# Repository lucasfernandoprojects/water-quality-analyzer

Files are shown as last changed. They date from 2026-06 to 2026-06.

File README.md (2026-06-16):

# ESP32 Water Quality Analyzer

An open-source water quality analyzer built with an ESP32 that estimates the pollution level of water samples by combining three different sensors. Results are displayed in real time on the Arduino IDE Serial Monitor.

> **This project was kindly sponsored by [Elecrow](https://www.elecrow.com/pcb-assembly.html?idd=5) - a leading provider of open-source hardware and manufacturing services. They offer everything from ESP32 development boards to professional PCB assembly, CNC machining, and more. I highly recommend checking them out for your next project.**

<div style="display: flex; flex-wrap: wrap;">
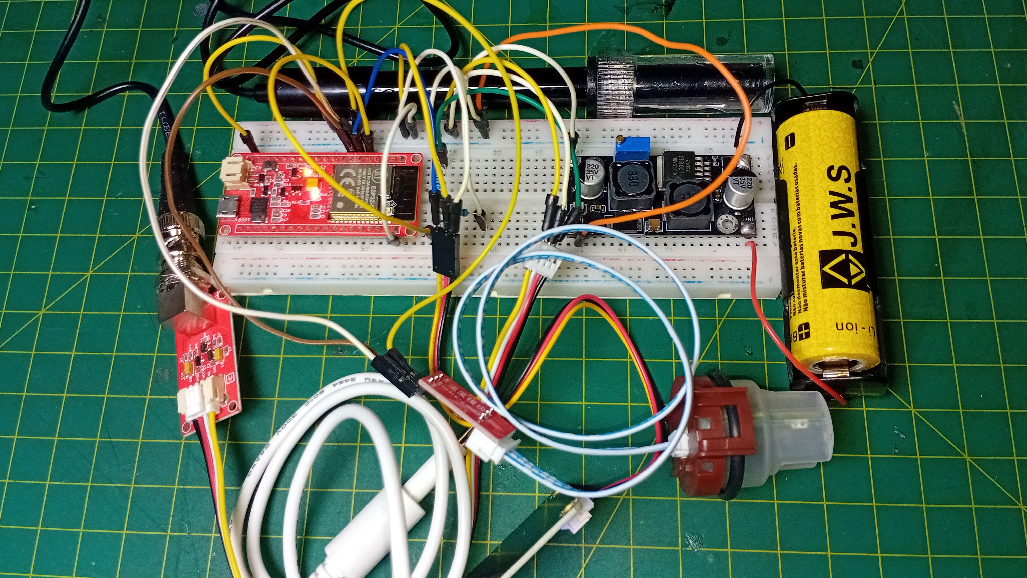
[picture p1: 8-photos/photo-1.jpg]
    
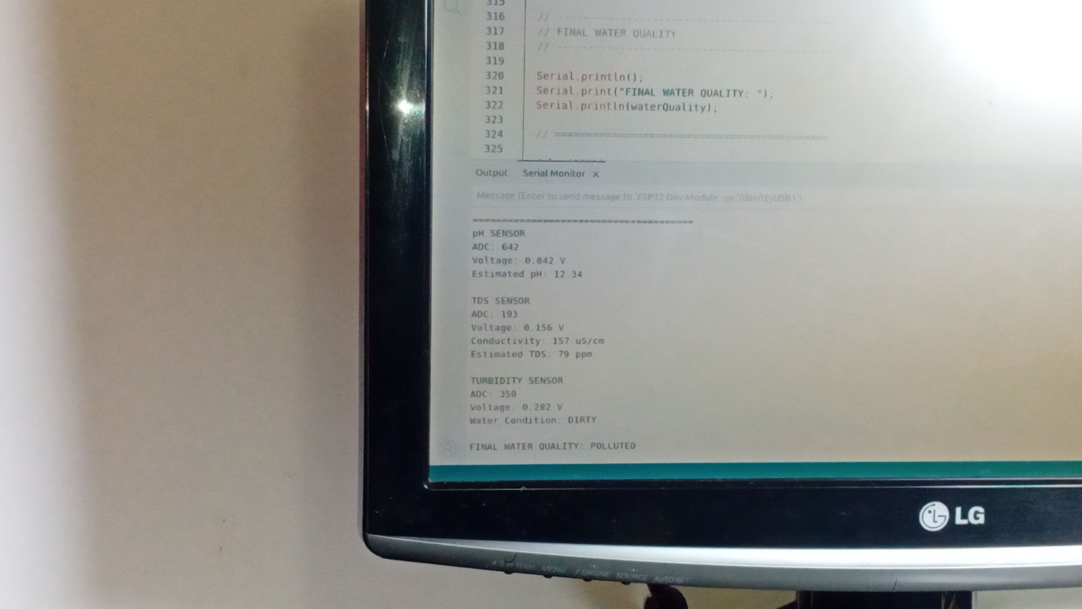
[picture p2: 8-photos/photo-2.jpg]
    
</div>

---

## 📺 Watch the Full Build Video

A complete walkthrough of this project, from wiring to real-world testing on urban rivers, is available on [YouTube](https://www.youtube.com/watch?v=ioxa7Pzs5dA). The video covers component selection, sensor calibration, code upload, and field results.

---

## 🧰 Components

| Component | Notes |
|---|---|
| ESP32 | Main microcontroller |
| pH Sensor | Analog output, requires voltage divider |
| Turbidity Sensor | Analog output |
| TDS Sensor | Analog output |
| Step-up Converter | Regulated 5V supply for the system |
| 21700 Li-ion Battery | Power source |
| 47kΩ & 75kΩ Resistors | Voltage divider for pH sensor |
| Breadboard + Jumper Wires | Prototyping |

**Estimated cost (as of June 2026):** ~$50 USD for components, excluding shipping and import fees.

### Calibration Solutions Required

- pH buffer solutions: pH 4, pH 7, and pH 10
- Conductivity solution: 1413 µS/cm

**Estimated cost:** at least ~$30 USD, excluding shipping and taxes.

<div style="display: flex; flex-wrap: wrap;">
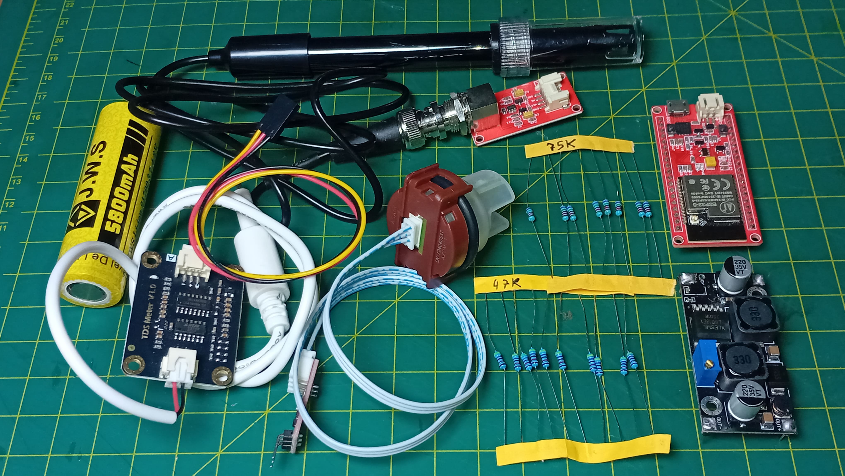
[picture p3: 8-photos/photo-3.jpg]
    
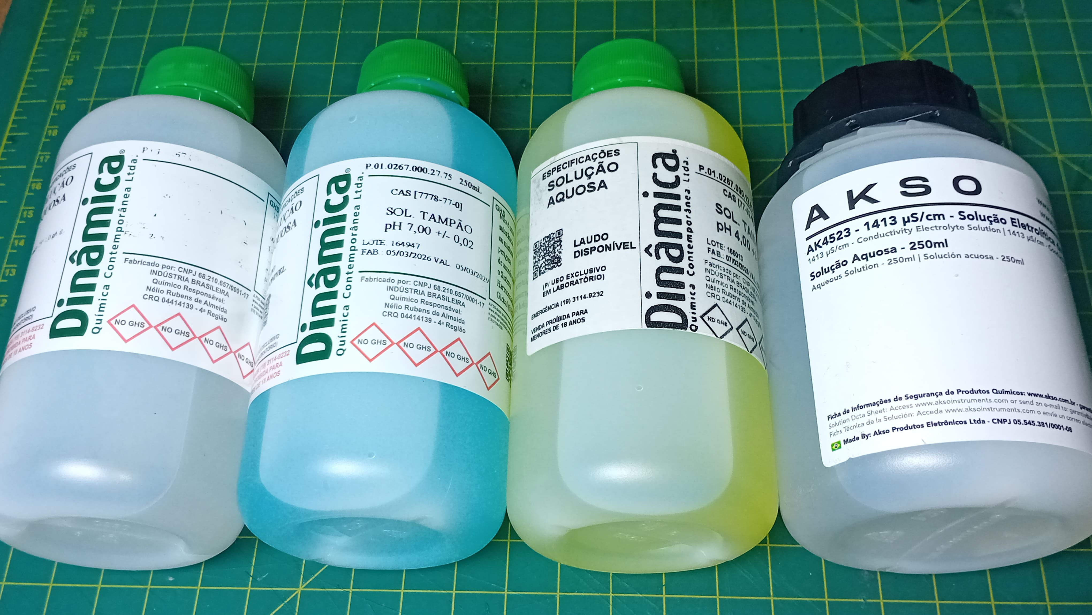
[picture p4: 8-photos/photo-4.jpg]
    
</div>

---

## 🔌 Wiring

| Sensor | GPIO Pin |
|---|---|
| pH Sensor (via voltage divider) | GPIO 34 |
| TDS Sensor | GPIO 35 |
| Turbidity Sensor | GPIO 32 |

### Voltage Divider (pH Sensor)

The pH sensor used in this project can output signals up to 5V, which exceeds the safe input voltage for the ESP32. A voltage divider built with a 47kΩ and a 75kΩ resistor reduces the signal to approximately 3V.

- Signal wire → 47kΩ resistor → GPIO 34
- 75kΩ resistor connected between signal line and GND

> If your pH sensor already outputs a voltage within the safe range for the ESP32, you can connect it directly without a voltage divider.

A full wiring schematic is available in the `schematic/` folder of this repository.

---

## ⚙️ Calibration

### pH Sensor

The pH sensor outputs an analog voltage, not a pH value directly. Calibration was performed using buffer solutions at pH 4, 7, and 10, which produced voltages ranging from approximately 1.2V down to 0.9V (voltage decreases as pH increases).

The relationship is linear, described by:

```
pH = m * V + b
```

Where:
- `V` = measured voltage
- `m` = slope (calculated: **-23.6**)
- `b` = offset (calculated: **32.2**)

Update these values in the code if your sensor produces different calibration readings.

### TDS Sensor

The TDS sensor outputs a voltage proportional to water conductivity. Using a 1413 µS/cm conductivity reference solution, a conversion factor was derived to translate sensor voltage into conductivity (µS/cm) and then into TDS (ppm).

<div style="display: flex; flex-wrap: wrap;">
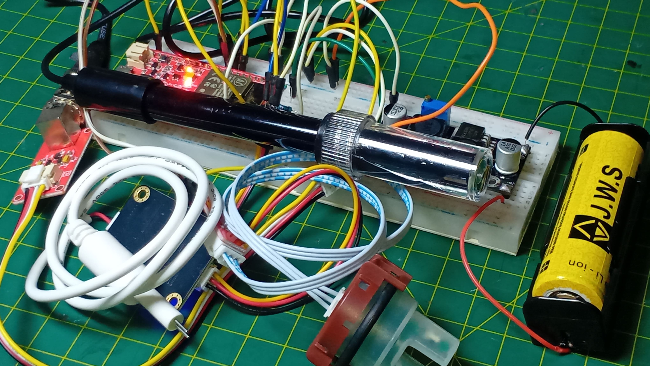
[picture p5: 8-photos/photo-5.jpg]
    
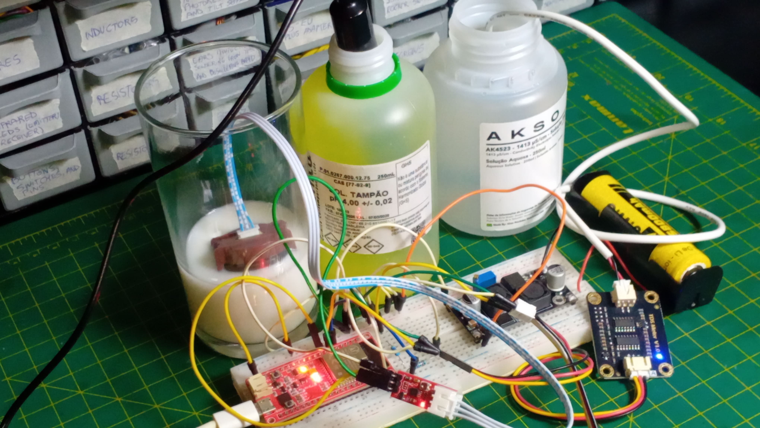
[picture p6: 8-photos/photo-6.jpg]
    
</div>

---

## 💻 Code

The complete Arduino sketch is available in this repository. To get started:

1. Download or clone this repository
2. Open the sketch in the Arduino IDE
3. Install the required libraries (listed in the sketch)
4. Update the calibration constants if needed
5. Select your ESP32 board and port, then click **Upload**
6. Open the Serial Monitor to see live readings

---

## 🧪 How It Works

The analyzer combines three measurements to classify water quality:

- **pH**: Detects acidity or alkalinity. Natural rivers typically fall between pH 6.5 and 8.5. Values outside this range may indicate contamination.
- **TDS (Total Dissolved Solids)**: Estimates the concentration of dissolved minerals and salts.
- **Turbidity**: Measures water clarity. Higher turbidity suggests suspended particles.

Based on these readings, the system outputs a pollution classification (e.g., `CLEAN`, `POLLUTED`) to the Serial Monitor.

---

## 🔬 Field Results

The analyzer was tested on water samples collected from two urban rivers in a large city that don't cross each other.

| Parameter | River 1 | River 2 |
|---|---|---|
| pH | ~12 | ~13 |
| Conductivity | ~157 µS/cm | ~175 µS/cm |
| Turbidity | Low (~0.3V) | Higher (~0.8V) |
| Classification | POLLUTED | POLLUTED |

Both samples showed highly alkaline pH values (above 12), which is far outside the range of natural water. While hobby-grade sensors have inherent limitations and laboratory testing would be needed to confirm exact values, these results - combined with visual observations such as visible waste, suspicious discharge pipes, and an absence of wildlife - are consistent with significant water pollution.

<div style="display: flex; flex-wrap: wrap;">
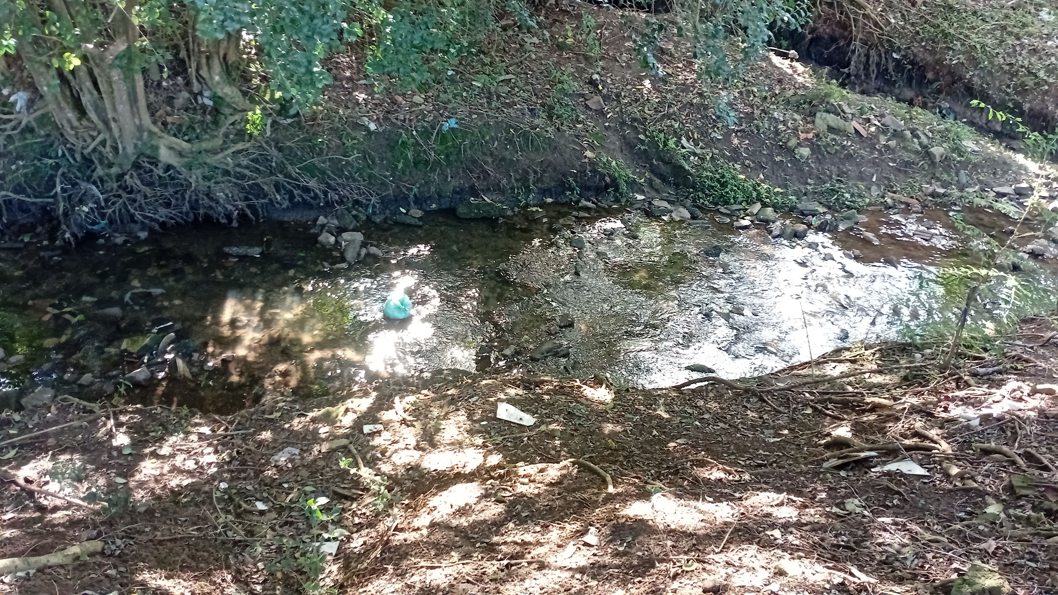
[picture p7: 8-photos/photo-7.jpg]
    
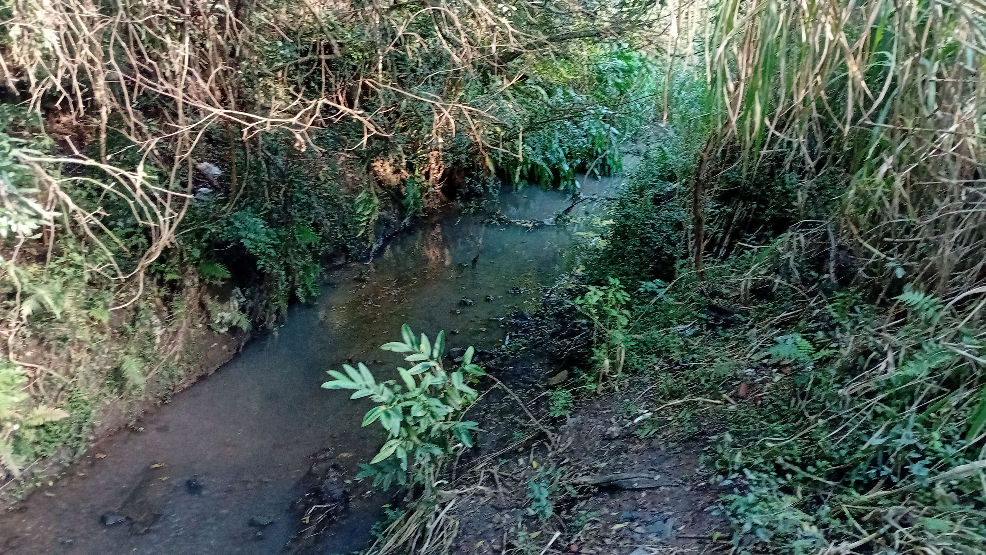
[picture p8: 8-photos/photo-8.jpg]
    
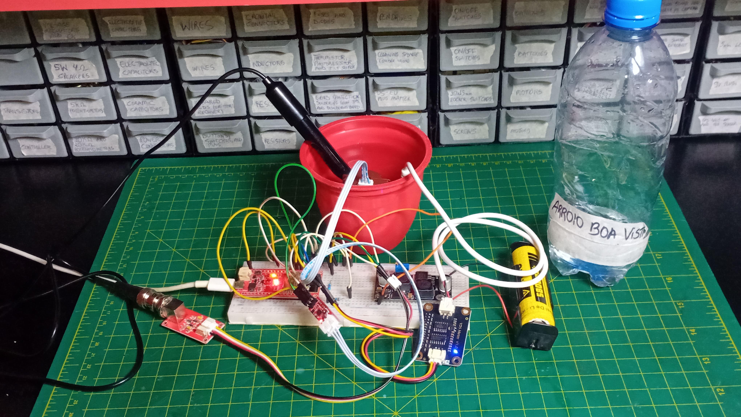
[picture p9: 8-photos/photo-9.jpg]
    
</div>

---

## 🛠️ Custom Shield PCB

After a failed attempt at a fully portable enclosure, a new custom **shield PCB** was designed to allow all three sensors to connect directly to the ESP32 without a breadboard or jumper wires. It contains battery protection (DW01A) and 5V boost converter (TPS61023DRLT).

The PCB design files (Gerber files, position files, and BOM) are included in this repository and are fully open-sourced for anyone to manufacture or modify.

<div style="display: flex; flex-wrap: wrap;">
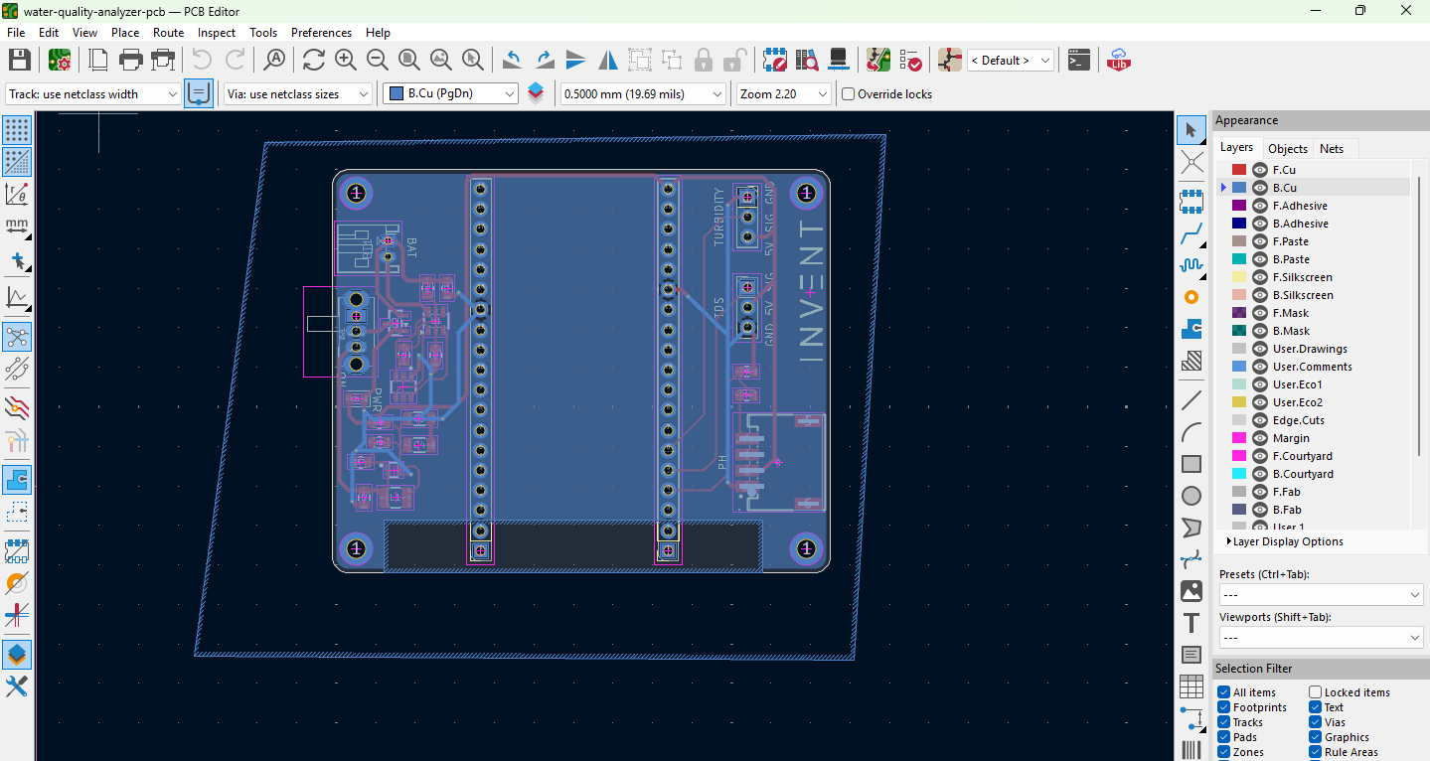
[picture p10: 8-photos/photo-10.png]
    
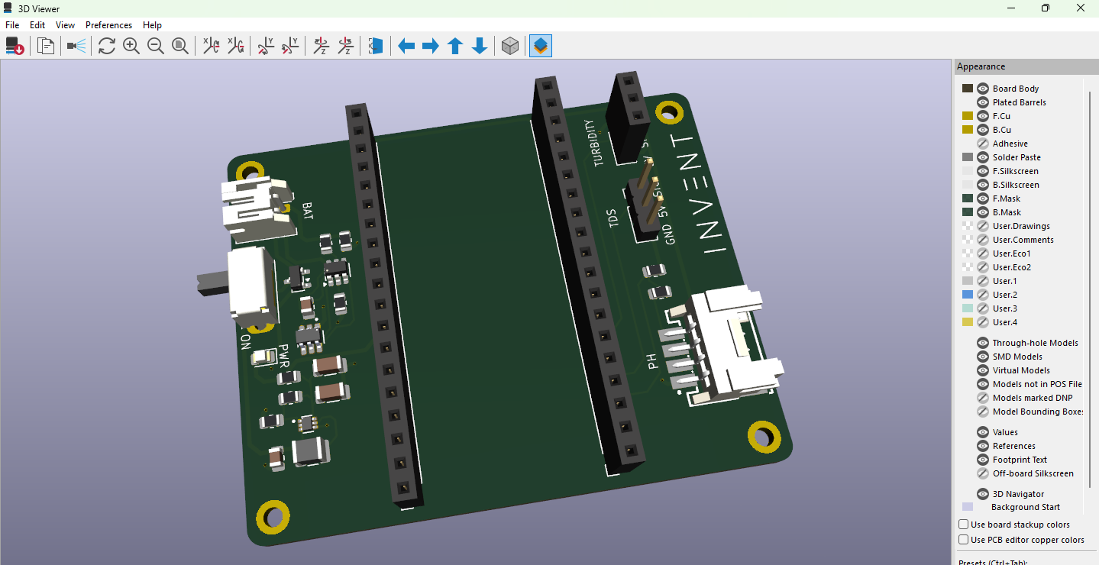
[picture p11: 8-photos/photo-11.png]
    
</div>

> [!NOTE]
> This PCB was designed to work with an [Elecrow ESP32 board](https://www.elecrow.com/esp32-wifi-ble-board.html). If you are using an ESP32 from another manufacturer, the pinout may be different. Be sure to check your board's pinout before connecting it on the PCB.

---

## 📁 Repository Structure

```
water-quality-analyzer/
├── 1-gerber/                         # Gerber files for PCB manufacturing
├── 2-drill/                          # Drill files for PCB manufacturing
├── 3-position/                       # Component position files
├── 4-components/                     # Component/BOM files
├── 5-model/                          # PCB 3D model files
├── 6-schematic/                      # Wiring schematic
├── 7-code/                           # Coding files
├── 8-photos/                         # Images of the project
├── LICENSE
├── README.md
```

---

## ⚠️ Limitations & Disclaimer

- Hobby-grade sensors provide estimated readings, not laboratory-grade measurements.
- Calibration accuracy directly affects result quality.
- Single-location, single-time-point samples are insufficient for definitive pollution assessments.
- Always validate results with certified laboratory equipment for any official or regulatory purpose.

---

## 📄 License

This project is open-source. Feel free to use, modify, and share it. If you build something based on this work, a credit or link back to this repository is always appreciated.

---

## 💬 Feedback & Contributions

Questions, suggestions, and pull requests are welcome! If you'd like to see a fully portable version of this analyzer with a touchscreen enclosure, let me know (it's on the roadmap).

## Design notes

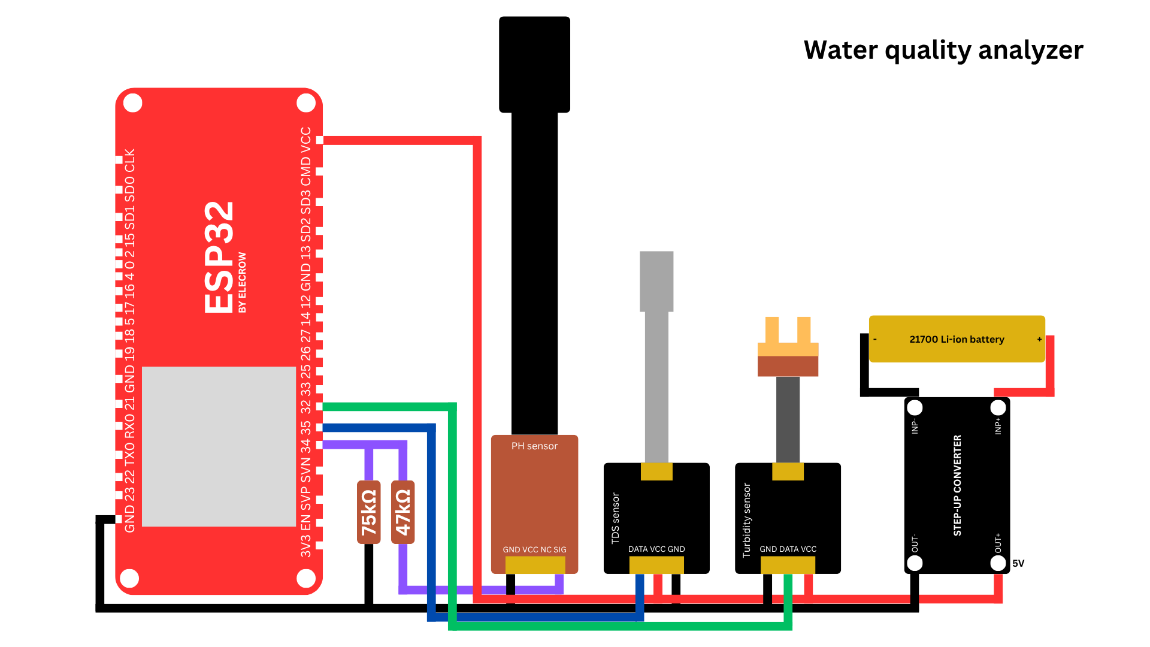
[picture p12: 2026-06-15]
6-schematic/schematic-breadboard-project.png

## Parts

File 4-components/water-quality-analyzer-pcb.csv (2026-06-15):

Id | Designator | Footprint | Quantity | Designation | Supplier and ref
1 | BT1 | JST_PH_S2B-PH-K_1x02_P2.00mm_Horizontal | 1 | Battery
2 | C1 | C_0805_2012Metric | 1 | 100nF
3 | C2 | C_0805_2012Metric | 1 | 10uF
4 | C3, C4 | C_1206_3216Metric | 2 | 22uF
5 | D1 | LED_0805_2012Metric | 1 | pwr led
6 | J1 | PinSocket_1x19_P2.54mm_Vertical | 1 | ESP32_LEFT_SIDE
7 | J2 | PinSocket_1x19_P2.54mm_Vertical | 1 | ESP32_RIGHT_SIDE
8 | J3 | CONN-SMD_4P-P2.00_ZX-HY2.0-4PWT | 1 | PH
9 | J4 | PinHeader_1x03_P2.54mm_Vertical | 1 | TDS
10 | J5 | PinSocket_1x03_P2.54mm_Vertical | 1 | TURBIDITY
11 | L1 | L_1210_3225Metric | 1 | 1uH
12 | Q1 | SOT95P280X145-6N | 1 | FS8205
13 | Q2 | SOT-23 | 1 | AO3401A
14 | R1 | R_0805_2012Metric | 1 | 100Ω
15 | R2 | R_0805_2012Metric | 1 | 1kΩ
16 | R3, R7 | R_0805_2012Metric | 2 | 100kΩ
17 | R4 | R_0805_2012Metric | 1 | 47kΩ
18 | R5 | R_0805_2012Metric | 1 | 75kΩ
19 | R6 | R_0805_2012Metric | 1 | 732kΩ
20 | R8 | R_0805_2012Metric | 1 | 470Ω
21 | SW1 | SW_Slide_SPDT_Angled_CK_OS102011MA1Q | 1 | on/off switch
22 | U1 | SOT-23-6 | 1 | DW01A
23 | U2 | SOT50P160X60-6N | 1 | TPS61023DRLT

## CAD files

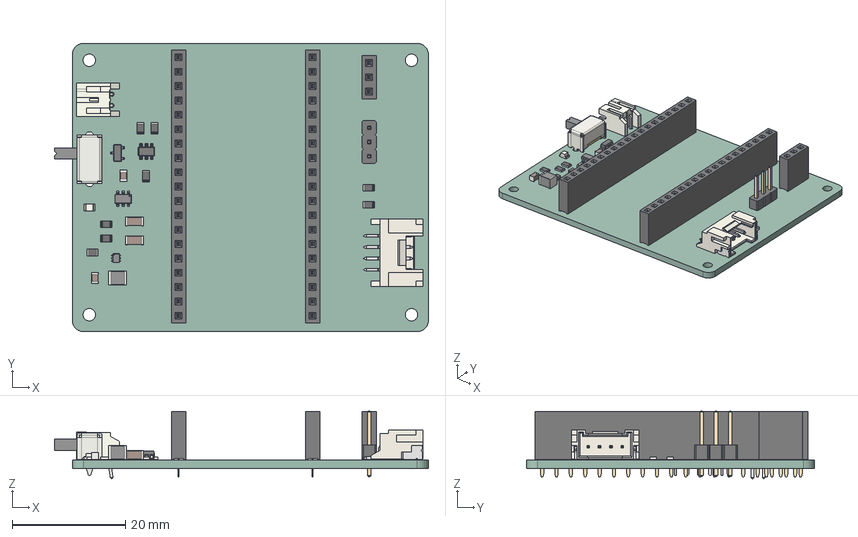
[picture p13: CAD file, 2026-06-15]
5-model/water-quality-pcb.step
66.2 x 51.0 x 11.9 mm
R_0805_2012Metric x 8
PinHeader_1x03_P254mm_Vertical
L_1210_3225Metric
PinSocket_1x19_P2.54mm_Vertical x 2
DRL6
C_0805_2012Metric x 2
C_1206_3216Metric x 2
PinSocket_1x03_P2.54mm_Vertical
SW_Slide_SPDT_Angled_CK_OS102011MA1Q
LED_0805_2012Metric
JST_S2B_PH_K
SOT-23-6
FS8205
SOT-23
water-quality-analyzer-pcb_PCB

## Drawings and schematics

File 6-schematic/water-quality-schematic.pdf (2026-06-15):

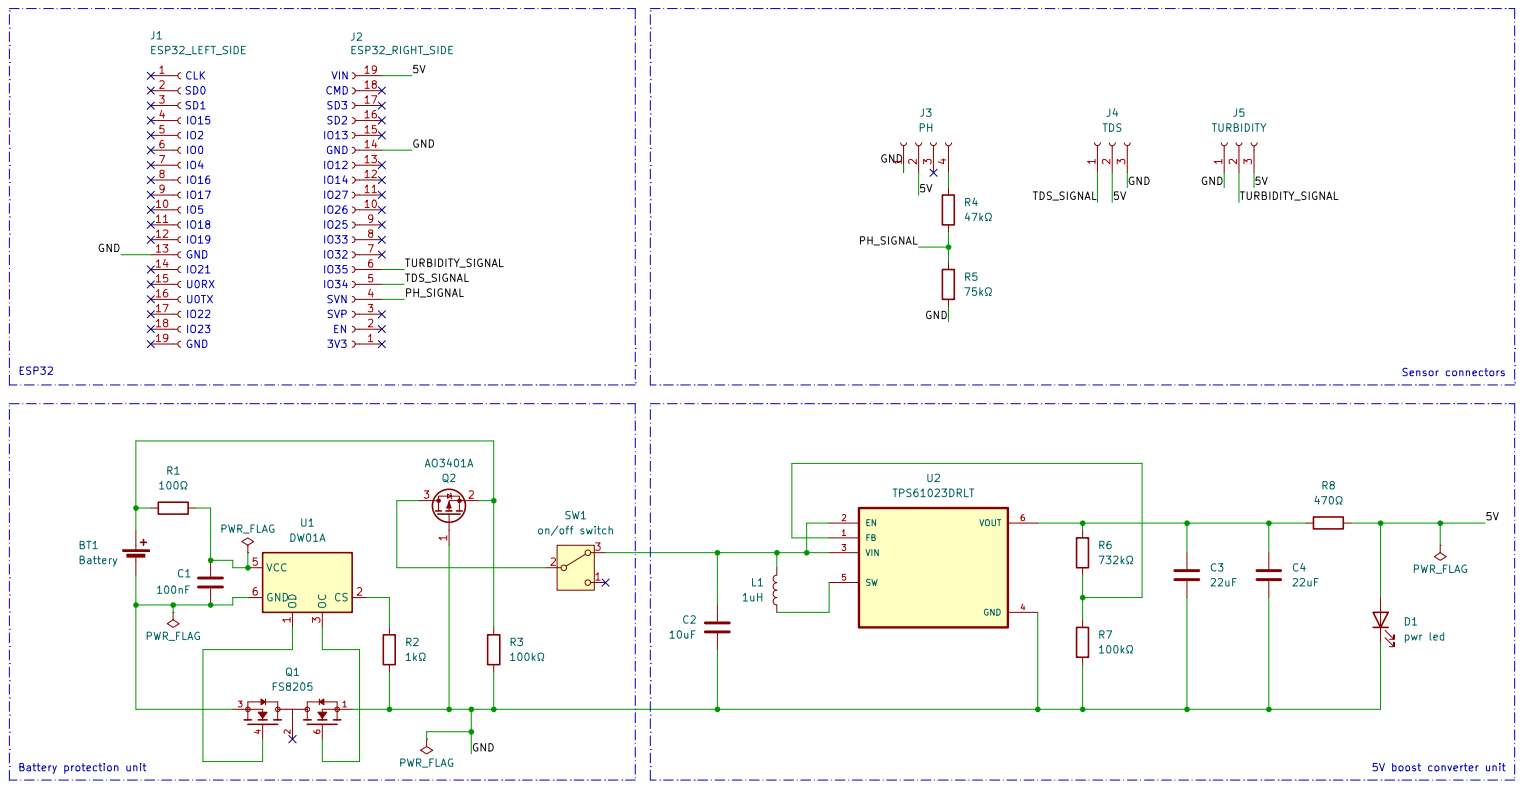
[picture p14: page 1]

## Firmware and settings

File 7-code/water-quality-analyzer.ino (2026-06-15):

// ===================================================
// ESP32 Water Quality Analyzer
// Fully Calibrated On The Test Sketch
// Created by Lucas Fernando
// Find my work at youtube.com/@lucasfernandochannel
// ===================================================

// ---------------- PIN DEFINITIONS ----------------
const int PH_PIN = 34;
const int TDS_PIN = 35;
const int TURBIDITY_PIN = 32;

// ---------------- ADC SETTINGS ----------------
const float ADC_VREF = 3.3;
const int ADC_RESOLUTION = 4095;

// ---------------- SAMPLING ----------------
const int NUM_SAMPLES = 20;

// ============================================
// pH SENSOR
// ============================================
const float PH_DIVIDER_FACTOR = (47.0 + 75.0) / 75.0;

// --------------------------------------------
// pH Calibration
// Measured values:
// pH 4  -> 1.193V
// pH 7  -> 1.053V
// pH 10 -> 0.939V
// --------------------------------------------
const float PH_SLOPE = -23.6;
const float PH_OFFSET = 32.2;

// ============================================
// TDS SENSOR
// ============================================
// Calibration:
// 1413 µS/cm solution

const float EC_SCALE_FACTOR = 1010.0;
const float TDS_FACTOR = 0.5;

// ============================================
// READ AVERAGED ADC
// ============================================

int readADC(int pin) {
  long sum = 0;

  for (int i = 0; i < NUM_SAMPLES; i++) {
    sum += analogRead(pin);
    delay(10);
  }

  return sum / NUM_SAMPLES;
}

// ============================================
// ADC TO VOLTAGE
// ============================================

float adcToVoltage(int adc) {
  return (adc * ADC_VREF) / ADC_RESOLUTION;
}

// ============================================
// WATER QUALITY CLASSIFICATION
// ============================================

String classifyWater(float pH, float tds, float turbidityVoltage) {
  int pollutionScore = 0;

  // --------------------------------------------
  // pH ANALYSIS
  // --------------------------------------------

  if (pH < 5.0 || pH > 9.0) {
    pollutionScore += 3;
  } else if (pH < 6.5 || pH > 8.5) {
    pollutionScore += 2;
  }

  // --------------------------------------------
  // TDS ANALYSIS
  // --------------------------------------------

  if (tds > 1000) {
    pollutionScore += 3;
  } else if (tds > 500) {
    pollutionScore += 2;
  } else if (tds > 300) {
    pollutionScore += 1;
  }

  // --------------------------------------------
  // TURBIDITY ANALYSIS
  // --------------------------------------------
  // Based on test measurements:
  // 0.283V = cleaner sample
  // 0.875V = dirtier sample
  //
  // Therefore:
  // Higher voltage = higher turbidity
  // --------------------------------------------

  if (turbidityVoltage > 1.20) {
    pollutionScore += 3;
  } else if (turbidityVoltage > 0.80) {
    pollutionScore += 2;
  } else if (turbidityVoltage > 0.40) {
    pollutionScore += 1;
  }

  // --------------------------------------------
  // FINAL CLASSIFICATION
  // --------------------------------------------

  if (pollutionScore <= 1) {
    return "CLEAN";
  } else if (pollutionScore <= 3) {
    return "MODERATE";
  } else if (pollutionScore <= 6) {
    return "POLLUTED";
  } else {
    return "VERY POLLUTED";
  }
}

// ============================================
// SETUP
// ============================================

void setup() {
  Serial.begin(115200);
  analogReadResolution(12);
  delay(1000);

  Serial.println();
  Serial.println("======================================");
  Serial.println("ESP32 Water Quality Analyzer");
  Serial.println("Fully Calibrated Test");
  Serial.println("======================================");
}

// ============================================
// MAIN LOOP
// ============================================

void loop() {
  // ============================================
  // READ ADC VALUES
  // ============================================

  int phADC = readADC(PH_PIN);
  int tdsADC = readADC(TDS_PIN);
  int turbidityADC = readADC(TURBIDITY_PIN);

  // ============================================
  // CONVERT TO VOLTAGES
  // ============================================

  float phVoltage = adcToVoltage(phADC) * PH_DIVIDER_FACTOR;
  float tdsVoltage = adcToVoltage(tdsADC);
  float turbidityVoltage = adcToVoltage(turbidityADC);

  // ============================================
  // pH CALCULATION
  // ============================================

  float pHValue = (PH_SLOPE * phVoltage) + PH_OFFSET;

  if (pHValue < 0) {
    pHValue = 0;
  } else if (pHValue > 14) {
    pHValue = 14;
  }

  // ============================================
  // TDS / CONDUCTIVITY
  // ============================================

  float conductivity_uS = tdsVoltage * EC_SCALE_FACTOR;
  float tdsPPM = conductivity_uS * TDS_FACTOR;

  // ============================================
  // TURBIDITY STATE
  // ============================================

  String turbidityState;

  if (turbidityVoltage < 0.40) {
    turbidityState = "CLEAN";
  } else if (turbidityVoltage < 0.80) {
    turbidityState = "MODERATE";
  } else if (turbidityVoltage < 1.20) {
    turbidityState = "POLLUTED";
  } else {
    turbidityState = "VERY POLLUTED";
  }

  // ============================================
  // GLOBAL WATER QUALITY
  // ============================================

  String waterQuality = classifyWater(pHValue, tdsPPM, turbidityVoltage);

  // ============================================
  // PRINT RESULTS
  // ============================================

  Serial.println();
  Serial.println("======================================");

  // --------------------------------------------
  // pH SENSOR
  // --------------------------------------------

  Serial.println("pH SENSOR");

  Serial.print("ADC: ");
  Serial.println(phADC);

  Serial.print("Voltage: ");
  Serial.print(phVoltage, 3);
  Serial.println(" V");

  Serial.print("Estimated pH: ");
  Serial.println(pHValue, 2);

  // --------------------------------------------
  // TDS SENSOR
  // --------------------------------------------

  Serial.println();
  Serial.println("TDS SENSOR");

  Serial.print("ADC: ");
  Serial.println(tdsADC);

  Serial.print("Voltage: ");
  Serial.print(tdsVoltage, 3);
  Serial.println(" V");

  Serial.print("Conductivity: ");
  Serial.print(conductivity_uS, 0);
  Serial.println(" uS/cm");

  Serial.print("Estimated TDS: ");
  Serial.print(tdsPPM, 0);
  Serial.println(" ppm");

  // --------------------------------------------
  // TURBIDITY SENSOR
  // --------------------------------------------

  Serial.println();
  Serial.println("TURBIDITY SENSOR");

  Serial.print("ADC: ");
  Serial.println(turbidityADC);

  Serial.print("Voltage: ");
  Serial.print(turbidityVoltage, 3);
  Serial.println(" V");

  Serial.print("Turbidity Level: ");
  Serial.println(turbidityState);

  // --------------------------------------------
  // FINAL WATER QUALITY
  // --------------------------------------------

  Serial.println();

  Serial.print("FINAL WATER QUALITY: ");
  Serial.println(waterQuality);

  // ============================================

  delay(2000);
}

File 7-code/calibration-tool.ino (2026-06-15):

// ===================================================
// ESP32 Water Quality Analyzer - Calibration Tool
// Created by Lucas Fernando
// Find my work at youtube.com/@lucasfernandochannel
// ===================================================

const int PH_PIN = 34;
const int TDS_PIN = 35;
const int TURBIDITY_PIN = 32;

const float ADC_VREF = 3.3;
const int ADC_RESOLUTION = 4095;

// Voltage divider used on pH sensor
const float PH_DIVIDER_FACTOR = (47.0 + 75.0) / 75.0;
const int NUM_SAMPLES = 100;

// ============================================

int readADC(int pin) {
  long sum = 0;

  for (int i = 0; i < NUM_SAMPLES; i++) {
    sum += analogRead(pin);
    delay(5);
  }

  return sum / NUM_SAMPLES;
}

// ============================================

float adcToVoltage(int adc) {
  return adc * ADC_VREF / ADC_RESOLUTION;
}

// ============================================

void setup() {
  Serial.begin(115200);
  analogReadResolution(12);
  delay(2000);

  Serial.println();
  Serial.println("===================================");
  Serial.println("ESP32 SENSOR CALIBRATION TOOL");
  Serial.println("===================================");
}

// ============================================

void loop() {
  int phADC = readADC(PH_PIN);
  int tdsADC = readADC(TDS_PIN);
  int turbidityADC = readADC(TURBIDITY_PIN);

  float phVoltage = adcToVoltage(phADC) * PH_DIVIDER_FACTOR;
  float tdsVoltage = adcToVoltage(tdsADC);
  float turbidityVoltage = adcToVoltage(turbidityADC);

  Serial.println();
  Serial.println("===================================");

  Serial.println("PH SENSOR");
  Serial.print("ADC: ");
  Serial.println(phADC);

  Serial.print("Voltage: ");
  Serial.print(phVoltage, 4);
  Serial.println(" V");

  Serial.println();

  Serial.println("TDS SENSOR");
  Serial.print("ADC: ");
  Serial.println(tdsADC);

  Serial.print("Voltage: ");
  Serial.print(tdsVoltage, 4);
  Serial.println(" V");

  Serial.println();

  Serial.println("TURBIDITY SENSOR");
  Serial.print("ADC: ");
  Serial.println(turbidityADC);

  Serial.print("Voltage: ");
  Serial.print(turbidityVoltage, 4);
  Serial.println(" V");

  Serial.println("===================================");

  delay(5000);
}

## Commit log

2026-06-15 Adding gerber files
    Adding all gerber files of the water quality analyzer project (PCB shield).
    [water-quality-analyzer-pcb-B_Cu.gbr, water-quality-analyzer-pcb-B_Mask.gbr, water-quality-analyzer-pcb-B_Paste.gbr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]
2026-06-15 Adding drill files
    Adding all drill files of the water quality analyzer project (PCB shield).
    [water-quality-analyzer-pcb-NPTH.drl, water-quality-analyzer-pcb-PTH.drl]
2026-06-15 Adding position files
    Adding all position files of the water quality analyzer project (PCB shield).
    [water-quality-analyzer-pcb-all-pos.csv, water-quality-analyzer-pcb-all-pos.xlsx, water-quality-analyzer-pcb-pnp_bottom.gbr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]
2026-06-15 Adding the BOM file
    Adding the BOM of the water quality analyzer project (PCB shield).
    [water-quality-analyzer-pcb.csv, water-quality-analyzer-pcb.xlsx]
2026-06-15 Adding the 3D model
    Adding the 3D model of the water quality analyzer project (PCB shield).
    [water-quality-pcb.step]
2026-06-15 Adding the schematic
    Adding the schematic file of the water quality analyzer project (PCB shield).
2026-06-15 Schematic breadboard project
    Add the schematic of the breadboard project (water quality analyzer).
2026-06-15 Schematic breadboard project
    The schematic of the breadboard project.
2026-06-16 PCBs
    Screenshots of the PCB project.
